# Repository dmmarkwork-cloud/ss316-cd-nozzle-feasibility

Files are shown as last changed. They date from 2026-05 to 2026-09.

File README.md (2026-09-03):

# SS316 Conical CD Nozzle: Thermal, Structural & DFM Assessment

Multiphysics analysis of an uncooled stainless-steel converging-diverging nozzle. The study answers a single question: **can SS316 survive the combined thermal and pressure loading at the design operating point?**

The short answer is yes against yield, with a FoS near 7 rather than the 42.7 reported in v1.0, and the binding questions are the startup transient and creep.

> **This is v2.0.** It supersedes v1.0, which reported a factor of safety of 42.70 at the throat. That figure was wrong by approximately 6x for two independent reasons: the wrong location was assessed, and the assessed quantity was not a classified stress. v1.0 is preserved under tag v1.0 and is not overwritten. See What changed in v2.0.

---

## Headline results

| Metric | Value | Source |
|---|---|---|
| Governing location | **Chamber-to-converging junction, converging side, inner surface** | Report §5.6 |
| Governing quantity | linearised membrane + bending (M+B); von Mises, axisymmetric straight | Report §5.5 |
| Governing stress (Mesh J3) | **29.611** | Report §5.6.1 |
| Mesh band, J1 to J3 | 29.611 to 30.010 MPa | Report §6.2 |
| SS316 yield at 526.83 °C (interpolated) | 210.73 MPa | SSINA Table 1 / Nickel Institute 9004 |
| Factor of safety against SS316 yield | **7.12 with a band 7.02 to 7.12** | Report §5.6.1 |
| Creep driver, primary membrane S₁ | 9.914 MPa | 	Report §5.6.3 |
| Through-wall ΔT at the junction| 1.26 K | Report §5.7 |
| Free axial thermal expansion (total deformation) | 1.711 mm over 183.44 mm | Report §5.8 |
| CFD peak wall y+ | 	1.74 (viscous sublayer resolved) | Report §4.2 |
| CFD mass imbalance | 	3.0 × 10⁻⁵ % | Report §4.3 |
| Discharge coefficient | 0.977 | Report §4.4 |

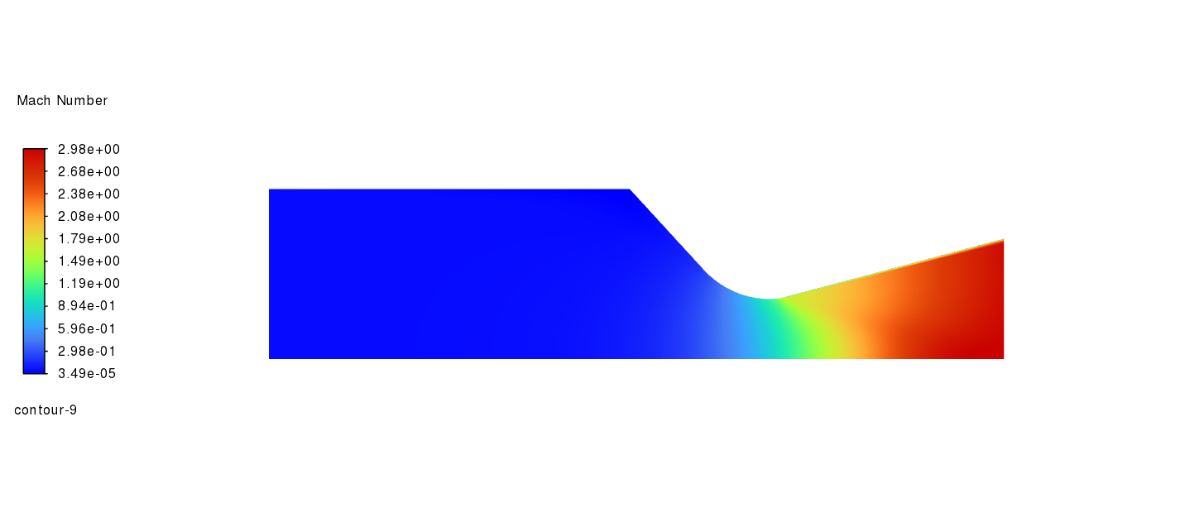
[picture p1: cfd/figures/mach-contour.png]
Mach number contour from the converged Fluent solution

**Mach number** contour from the converged Fluent solution Mach number contour, converged Fluent solution on the structured 88,800-cell mesh. Area-weighted exit Mach 2.85 against hand-calc 2.94, within 3.1% (validation gate passed). Peak 2.98 is the inviscid core value, not the bulk exit.

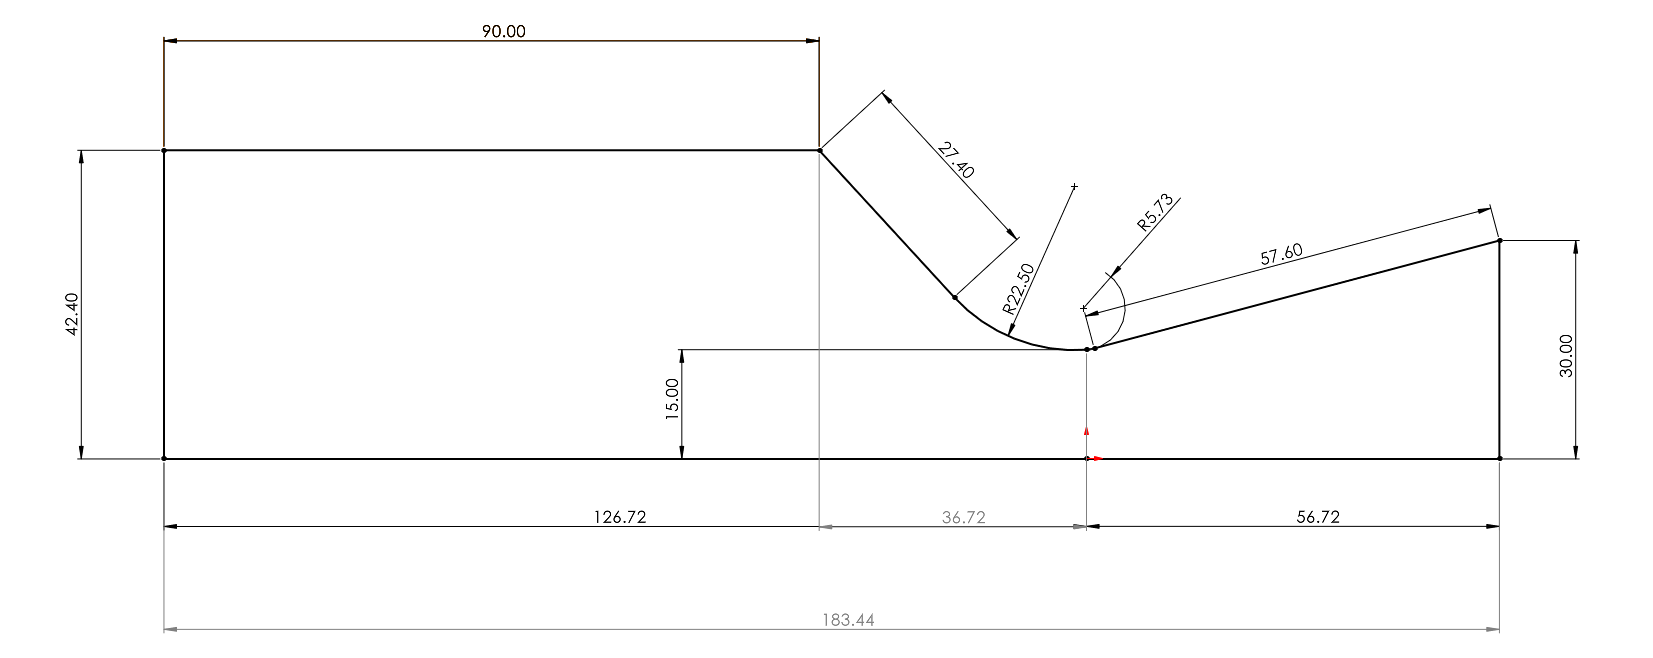
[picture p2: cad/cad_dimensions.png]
Nozzle half-section dimensions

**Nozzle half-section dimensions (mm)**. Throat radius 15 (nominal; as-built minimum 14.942 at −0.77 % area (see Geometry Freeze Disposition), exit radius 30 (ε = 4). Divergent side: 14.8° throat-to-exit chord angle (the straight diverging segment itself is 14.91°). Convergent side: a straight 47.43° taper from the chamber blended into the throat through an R22.5 arc. 4 mm wall.

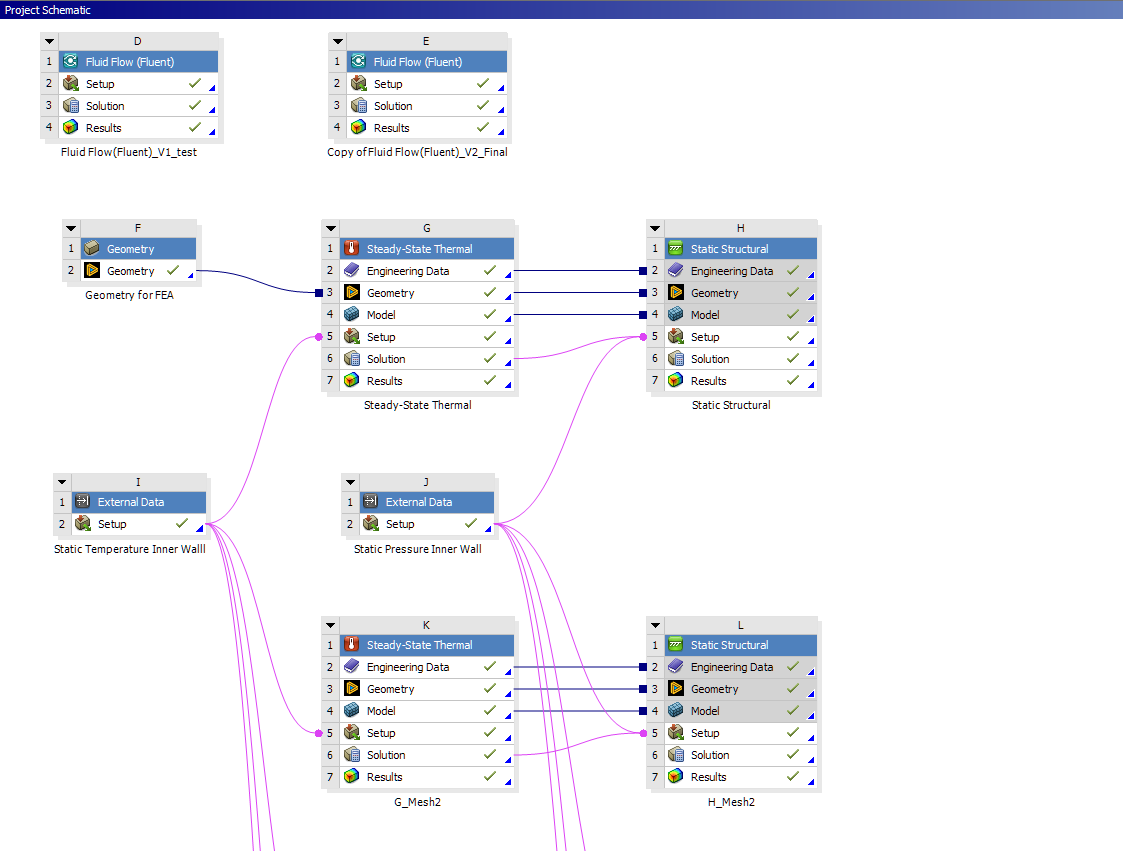
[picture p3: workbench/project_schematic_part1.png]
Workflow part 1

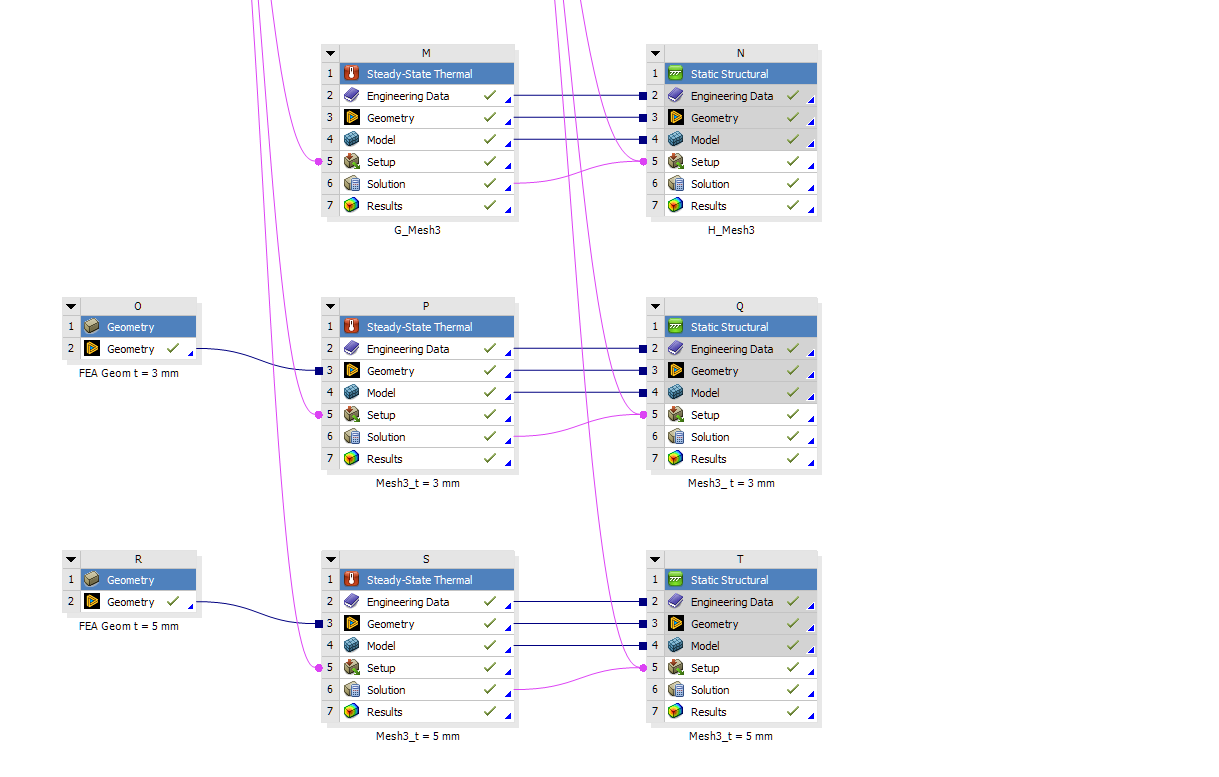
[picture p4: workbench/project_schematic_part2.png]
Workflow part 2

**One-way FSI chain:** two External Data systems feed a steady-state thermal and a static structural system, with explicit validation gates between phases.

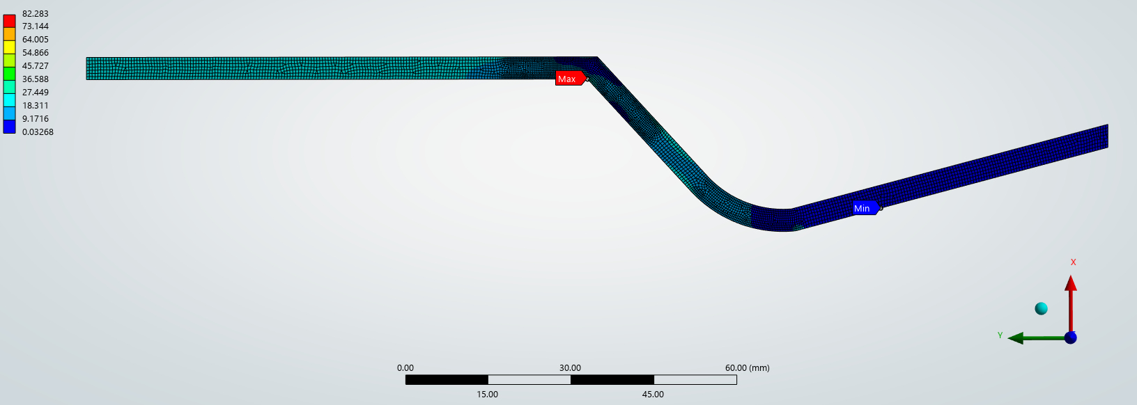
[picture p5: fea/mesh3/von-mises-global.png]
von Mises globa

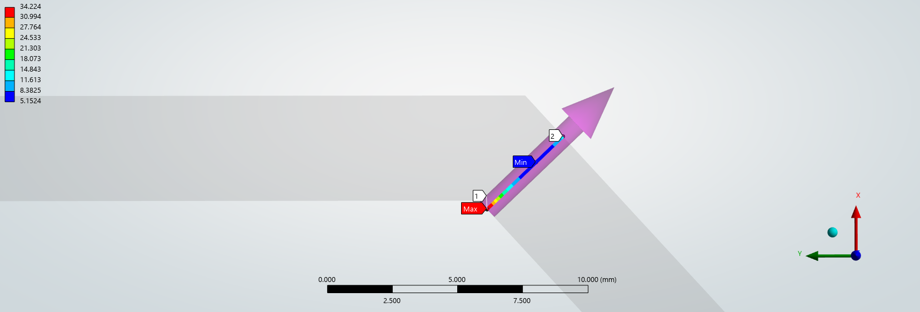
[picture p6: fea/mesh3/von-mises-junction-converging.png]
von Mises junction converging side

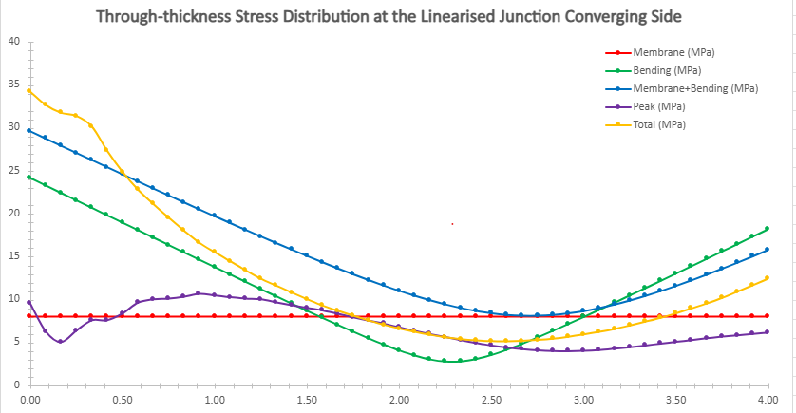
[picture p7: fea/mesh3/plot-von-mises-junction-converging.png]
von Mises junction converging side plot


**The 82.283 MPa maximum** is located at the unfilleted jucntion kink, is re-entrant and therefore singular, and is excluded from the assessment. The reported 29.611 is the linearised M+B (a seperate stress quantity that feeds combined tensor components into von Mises) on a through-thickness path adjacent to that corner. The v1.0 inlet-vertex displacement constraint singularity is absent; it was eliminated by moving the displacement constraint from a vertex to the full inlet edge.

**The binding failure modes are not yield.** The wall runs at approximately 527 °C at the junction, above the SS316 410 °C creep onset, with a non-relaxing primary membrane driver of 9.914 MPa. SS316 remains viable for short-duration prototype and ground-test firings at this operating point. Sustained or flight-rated operation requires the transient and creep work listed under Future work.

---

## Operating point

| Parameter | Value | Notes |
|---|---|---|
| Chamber pressure, P_c | 2 MPa | Working air, γ = 1.4 |
| Chamber temperature, T_c | 800 K | Within SS316 continuous-service limit (925 °C, oxidizing) |
| Exit pressure, P_e | 0.1 MPa | Sea-level design |
| Throat radius, R_t | 15 mm | |
| Area ratio, A_e/A_t | 4 | |
| Contraction ratio, A_c/A_t | 8 | From M_inlet ≤ 0.1 constraint (min ≥ 5.9) |
| Wall thickness, t | 4 mm | Baseline; sensitivity at 3/4/5 mm |
| Geometry | Conical C-D | Diverging straight taper 14.91° half-angle (14.8° throat-to-exit chord); converging straight taper 47.43° half-angle, blended into the throat by an R22.5 arc (no junction fillet). As-built, verified from CAD/STEP — see `docs/Geometry_Freeze_Disposition.md` |
| Material | SS316 | Uncooled, temperature-dependent properties |

All pressures reported in v2.0 are **absolute**. Any figure carrying a gauge scale belongs to v1.0.

**Material precedent:** the IJIRSET 2019 H₂O₂ monopropellant thruster (Deif et al.) uses SS316 in a similar uncooled configuration. Conditions differ (lower chamber pressure, smaller throat, pulsed, different working fluid), so it supports material precedent only.

---

## Tools & environment

| Phase | Tool | Notes |
|---|---|---|
| Hand calculations | Jupyter + handcalcs | Symbolic → numeric trace |
| CAD geometry | SolidWorks → SpaceClaim | 2D axisymmetric surface body |
| CFD | ANSYS Fluent 2026 | 2D axisymmetric, density-based coupled, k-ω SST |
| CFD mesh | ANSYS Meshing (classic); 2D Fluent system | Structured mapped quad, 444 × 200, 88,800 cells. Replaces Fluent Meshing in v1.0 |
| FEA | ANSYS Mechanical 2026 | Steady-state thermal + static structural |
| FEA Mesh | Fluent Meshing (CFD), Mechanical (FEA) | Quad-dominant, junction-refined ladder J1/J2/J3 |

---

## Analysis workflow

Six phases, each gated by validation against the previous phase.

| # | Phase | Status | Deliverable |
|---|---|---|---|
| 1 | Hand calculations (isentropic, area-Mach, T_aw) | Complete | `notebooks/cd-nozzle-handcalc-checkpoint.ipynb` |
| 2 | SolidWorks geometry (2D axisymmetric profile, 4 mm wall offset) | Complete | `cad/conical_v1_sketch.SLDPRT` |
| 3 | CFD: ANSYS Fluent, 2D axisymmetric, k-ω SST | Complete | `docs/Phase3_CFD_Summary.md` |
| 4 | FEA: one-way FSI → ANSYS Mechanical thermal-structural | Complete | `docs/Phase4_FEA_Summary_v3.md` |
| 5 | Mesh convergence study | Complete | `docs/Phase5_Convergence_Study_v2.md`, `notebooks/convergence_study_handcalc-checkpoint.ipynb` |
| 6 | Wall-thickness sensitivity study | Complete | `docs/Phase5b_Sensitivity_Study.md`, `notebooks/wall_thickness_sensitivity-checkpoint.ipynb` |

The one-way FSI uses Fluent wall outputs (static temperature, static pressure) mapped onto the FEA mesh through ANSYS Workbench **External Data systems**.

---

## Key findings

1. **The chamber-to-converging junction governs, not the throat.** At the unfilleted cylinder-to-convergent discontinuity, linearised M+B is 29.611 MPa against 17.183 MPa at the throat fillet: a 1.72x difference. 

2. **Bending dominates, and increasing thickness improves FoS, reversing the v1.0 trend.** Bending contributes 71 to 77% of M+B. Junction FoS is 4.62 / 7.12 / 10.18 for t = 3 / 4 / 5 mm. The v1.0 throat FoS values of 53.27 / 42.70 / 33.96 are withdrawn. Thermal bending is real but contributes only 4 to 16% at the junction. At the throat, the pressure state is anticlastic and nearly stress-free, leaving thermal stress as the dominant component there.

3. **The governing metric does not converge monotonically, so the result is reported as a band.** Governing von Mises M+B changes only −0.08% then −1.25% across J1/J2/J3.

4. **Steady-state thermal loading is small.** Natural convection accounts for 99.64% of the thermal resistance. Of the available 500 K wall-to-ambient difference, approximately 498 K occurs across the external film and only ~1 K across the wall.

5. **The same thermal boundary condition fails validation in the axial profile.** The imported wall temperature spans only 17 K, versus approximately 56 K expected from recovery theory, and exceeds the 800 K stagnation temperature by up to 9 K. Thus, a realistic axial thermal load is missing. At the junction, Saint-Venant decay bounds the consequence (91 mm extent vs. 13.3 mm decay length); in the divergent section, it does not. This is reported as a failed validation gate, not re-scoped into a pass.

6. **Seventeen FEA validation gates were applied, with two failures.** The validation included independent equilibrium checks: net axial thrust vs. CFD wall integral (0.20%) and axial membrane identity F/A_ring (0.001%). The two failed gates were throat path-length validation and imported wall temperature vs. recovery theory. Their consequences are explicitly bounded rather than hidden.

---

## The Design for Manufacturing (DFM) Package

The feasibility result above is only useful if the part can be made and inspected. The analysis is therefore carried into a **fabricable engineering package**: a GD&T'd, toleranced drawing set for the inlet joint, tolerance stack-ups that close against the frozen FEA geometry, a machining route, an inspection plan, a BOM, and a mock supplier RFQ.

**Scope** is a short-duration, ground-test prototype, quantities 1 to 5. Drawing set is ASME Y14.5-2018, first-angle, A2, issued Revision C (2026-08-13).

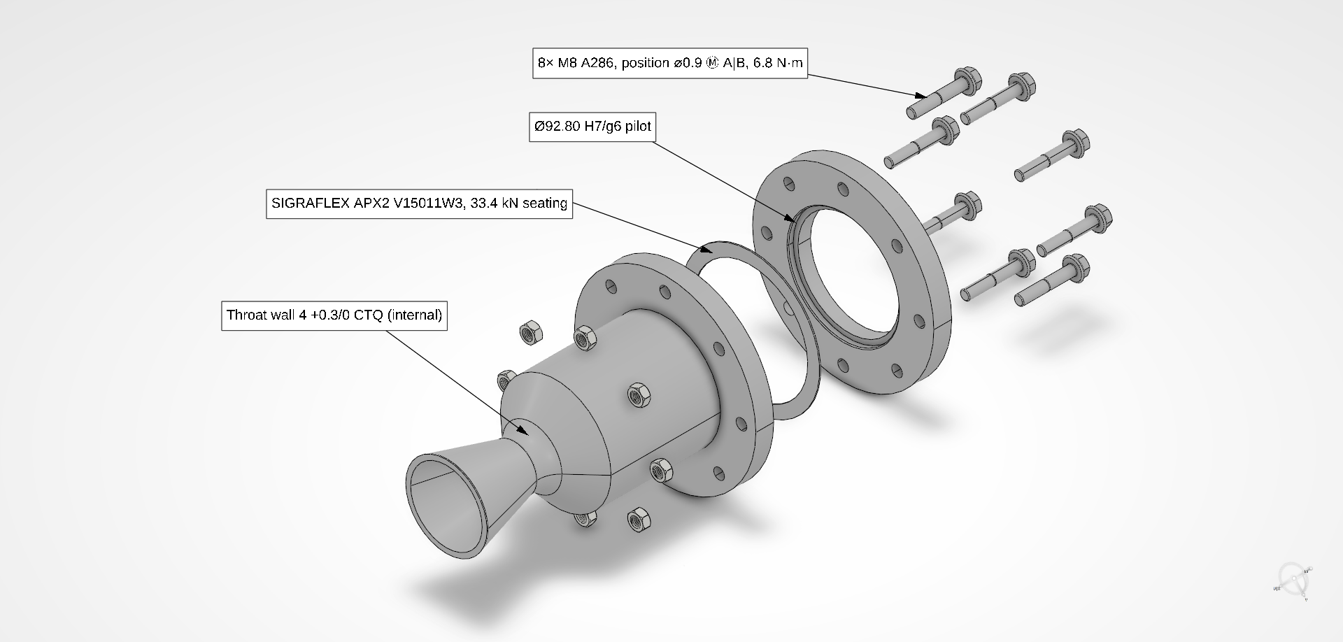
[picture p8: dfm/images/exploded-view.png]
Exploded view of the inlet joint assembly

Inlet-joint assembly (CDN-000). Nozzle body, flexible-graphite gasket, mounting flange, 8 x M8 A286 floating fasteners.

| Sheet | Part | Key controls |
|---|---|---|
| [CDN-001](dfm/drawing/CDN-001.pdf) | C-D Nozzle Body | frozen internal contour by surface profile 0.2 A\|B + total runout 0.05 A\|B; throat wall **4 +0.3/0 (CTQ)**; pilot Ø92.80 g6 |
| [CDN-002](dfm/drawing/CDN-002.pdf) | Mounting Flange | register bore Ø92.80 H7 with ⊥0.05 A; seat flatness 0.05 |
| [CDN-000](dfm/drawing/CDN-000.pdf) | Inlet-joint Assembly | ballooned BOM, interface notes, bolt torque 6.8 N·m cold |

### Four main decisions that carry this package

1. **Pilot locates, bolts clamp.** A single Ø92.80 H7/g6 locational-clearance fit centres the flange (Datum B); the 8 x M8 fasteners float and only clamp, positioned at MMC.
2. **The CTQ is the throat wall, and it is not a yield argument.** The 4 +0.3/0 band comes from creep life at ~530 °C, pressure-boundary minimum material, and machining minimum. The sensitivity study confirms the whole band is structurally free (FoS ≈ 40 across it), which is exactly why the tolerance had to be justified on other grounds.
3. **The stacks close, with margin.** Worst-case 1-D concentricity 0.060 mm against a 0.10 mm limit (1.68x); the bolt pattern assembles at strict MMC with no reliance on bonus tolerance.
4. **Every value is traceable.** Each dimension, tolerance and fit is tied to a source and a claim tier in the [value register](dfm/docs/value-register.md) and [`SOURCES.md`](dfm/sources/SOURCES.md), down to the gasket bolt load taken from ASME BPVC VIII-1 Mandatory Appendix 2.

**Full package: [`dfm/README-dfm.md`](dfm/README-dfm.md)**

---

## Scoping & limitations

- **No creep model.** The wall runs above the SS316 creep threshold. The driver is the primary membrane S₁ of 9.914 MPa, not the 29.611 MPa headline, because secondary bending relaxes under sustained load.
- **Steady-state only.** No transient startup/shutdown or thermal-fatigue/cyclic loading; The short-duration-firing conclusion does not cover cyclic life.
- **One-way FSI only.** No structural deformation feedback into CFD. Standard for preliminary analysis at this fidelity.
- **No junction fillet.** The sharp re-entrant corner makes Peak singular and mesh-dependent, so Peak and Total are excluded at that location. 
- **CFD rests on a single mesh** Iterative convergence demonstrated and five physical gates pass; discretisation error is not quantified.
- **Governing path is non-monotone under mesh refinement.** No valid Richardson order or GCI on the reported quantity. Reported as a band, 7.02 to 7.12.
- **Adiabatic-wall CFD → imposed T_aw on FEA.** Conservative; credits no wall-side conduction or radiation relief.
- **2D axisymmetric.** No asymmetric loads. Acceptable for axisymmetric geometry and required by the license cell cap.
- **Outer-wall convection h = 10 W/m²·K.** Still-air natural convection; conservative for a test stand where exhaust-plume entrainment would add convective relief.

---

## Operating point

| Parameter | Value | Notes |
|---|---|---|
| Chamber pressure, P_c | 2 MPa | Working air, γ = 1.4 |
| Chamber temperature, T_c | 800 K | Within SS316 continuous-service limit (925 °C, oxidizing) |
| Exit / back pressure, P_e | 0.060 MPa absolute | 60,000 Pa. Corrects the v1.0 record of 0.1 MPa; consistent with isentropic 59,574 Pa |
| Throat radius, R_t | 15 mm | |
| Area ratio, A_e/A_t | 4 | |
| Contraction ratio, A_c/A_t | 8 | From M_inlet ≤ 0.1 constraint (min ≥ 5.9), NASA SP-8120 |
| Wall thickness, t | 4 mm | Baseline, normal offset; sensitivity at 3/4/5 mm |
| Geometry | Conical C-D | 14.8° divergent half-angle; converging wall 46.25° from the axis, blended into the throat by an R22.5 arc; **no junction fillet** |
| Material | SS316 | Uncooled, temperature-dependent E and α |
| Allowable basis | Typical short-time values | Not specified-minimum. Flagged as future work |

All pressures reported in v2.0 are **absolute**. Any figure carrying a gauge scale belongs to v1.0.

Material precedent: the IJIRSET 2019 H₂O₂ monopropellant thruster (Deif et al.) uses SS316 in a similar uncooled configuration. Conditions differ (lower chamber pressure, smaller throat, pulsed, different working fluid), so it supports material precedent only.

---

## What changed in v2.0?

| # | Change | Effect |
|---|---|---|
| 1 | Governing location corrected: throat → chamber-to-converging junction | 8.602 → 29.611 MPa, 3.44x |
| 2 | Stress quantity corrected: body-scoped von Mises probe → linearized M+B | 4.917 → 8.602 MPa at the throat, 1.75x |
| 3 | **Combined effect on the headline** | **FoS 42.70 → 7.12** |
| 4 | Kinematic constraint: single vertex → full chamber-end edge | Constraint singularity removed; end-region M+B 91.34 → 19.54 MPa |
| 5 | Implementation of linearization set to Axisymmetric Straight on all objects | Converging-side M+B +12%; changed which side of the kink governs |
| 6 | Allowable evaluated at the governing-location temperature, 526.83 °C | 209.95 → 210.73 MPa |
| 7 | Mesh convergence re-scoped from throat to junction (J1/J2/J3) | Governing quantity now has convergence evidence, reported as a band |
| 8 | Thickness sweep re-scoped from throat to junction | Trend direction **reverses**; "FoS > 33 throughout" withdrawn; t = 3 mm gives 4.62 |
| 9 | FEA validation gates expanded from 3 to 17 | Two independent equilibrium closures, a formulation check, a thermal handoff check |
| 10 | CFD mesh replaced: unstructured hybrid (15,757 cells) → structured mapped quad (88,800 cells) | 100% quad, zero non-conformal interfaces, cell/node/face counts closed exactly |
| 11 | CFD near-wall clustering rebuilt: first cell 0.01 mm → 1.71 µm | Peak y+ 18 → 1.74; viscous sublayer resolved; retires limitation L1 |
| 12 | CFD mass imbalance 0.04% → 3.0 × 10⁻⁵ % | Three orders of magnitude |
| 13 | CFD pressure convention: gauge at 100 kPa reference → absolute at 0 Pa operating | Removes gauge/absolute ambiguity across all reported pressures |
| 14 | Discharge coefficient added as a CFD validation gate | Direct test of throat boundary-layer resolution; C_d = 0.977 |

**Why v1.0 was wrong but internally consistent** The v1.0 mesh convergence study was sound: four of five quantities of interest converged to within 1%. The assessment lies on a wrong probe scope, which is not a classified stress and not governing location. A converged wrong quantity is still wrong quantity. Therefore, investigating a non-governing location (throat) was not the correct approach and should have prompted a check of location and classification before publising.

---

## Repository structure

```
C-D-Nozzle/
├── README.md                                           # This file
├── docs/
│   ├── ss316_properties.md
│   ├── Geometry_Freeze_Disposition.md                  # Frozen as-built contour + deviation disposition
│   ├── Phase3_CFD_Summary.md
│   ├── Phase4_FEA_Summary_v2.md
│   ├── Phase4_FEA_Summary_v3.md
│   ├── Phase5_Convergence_Study_v2.md
│   └── Phase5b_Sensitivity_Study.md
├──dfm/
|   ├── calculations                                    # gasket loads, stack-up analysis and plot
|   ├── docs                                            # drawing data, specs, plans, records,  registers, decisions
|   ├── drawing                                         # official drawing sheets; CDN-000, CDN-001, CDN-002
|   ├── fair                                            # first article inspection request forms
|   ├── images                                          # isometric, inspection, and clash views
|   ├── revisions                                       # drawing sheet revision block records
|   ├── sources                                         # package source ledger (standards, materials, methods)
|   └── README-dfm.md                                   # DFM package summary
├── notebooks/
│   ├── cd-nozzle-handcalc-checkpoint.ipynb             # Phase 1
│   ├── convergence_study_handcalc-checkpoint.ipynb     # Phase 5
│   └── wall_thickness_sensitivity-checkpoint.ipynb     # Phase 6
├── cad/
│   ├── cad_dimensions.png
│   ├── conical_v1_sketch.SLDPRT                        # SolidWorks source 2D/3D
│   ├── conical_v1_sketch.STEP                  
│   ├── conical_v2_spaceclaim.sketch.scdocx             # SpaceClaim geometry
│   ├── inlet_side.png                       
│   ├── isometric.png                           
│   ├── outlet_side.png                        
│   └── right_side.png                          
├── cfd/
│   ├── case_data/                                      # CFD Fluent data and setup
│   ├── figures/                                        # results, plots, contours
│   ├── exports/                                        # wall_temperature_v2.xy, wall_pressure_v2.xy, BC, and loads
│   └── mesh/                                           # Mesh data
├── fea/
│   ├── mesh1/                                          # Solved figures (von Mises, ΔT, deformation) and Mechanical data in mesh 1
│   ├── mesh2/                                          # Solved figures (von Mises, ΔT, deformation) and Mechanical data in mesh 2
│   └── mesh3/                                          # Solved figures (von Mises, ΔT, deformation) and Mechanical data in mesh 3
├── workbench/
    ├── project_schematic_part1.png                     # Analysis workflow
    └── project_schematic_part2.png
└── report/
    └── ss316_nozzle_report.pdf                         # Comprehensive report of the project
```

---

## Related work

- **`gas-vessel-fea`** — prior portfolio piece. Pressure vessel mesh convergence study; same methodological framework applied to a simpler geometry.

---

## Author
Mark Lorenz Yamanaka · Tsukuba · 2026

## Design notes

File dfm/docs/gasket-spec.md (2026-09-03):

# Gasket Specification: Inlet Joint Seal

One consolidated spec for the inlet-joint gasket, so the model, the drawing BOM and the RFQ all draw from one source.

**Item:** CDN-000 BOM item 5. **Confirmed part: SGL SIGRAFLEX APX2 HOCHDRUCK V15011W3.**

> **Claim Tier**
> - **T1** verified against the frozen analysis
> - **T2** derivable/reproducible
> - **T3** engineering judgment, stated as such
> - **T4** strategy, never on the drawing

| Item | Value | Tier | § |
|---|---|---|---|
| Grade | SIGRAFLEX APX2 HOCHDRUCK V15011W3, inhibited reinforced graphite | T2 | 1 |
| Dimensions | Ø92.8 ID × Ø112.8 OD × 1.5 mm free, plain ring | T2 | 2 |
| Compressed, seated | ~1.0 to 1.1 mm | T2 | 2 |
| Effective width (b), reaction diameter (G) | 5.0 mm, 102.8 mm | T2 | 2, 6 |
| Seat temperature | ~527 °C in air, confined | T1 | 3 |
| Governing temperature limit | 580 °C, datasheet maximum | T2 | 4 |
| Seat finish | Ra 3.2 to 6.3 µm, serrated, not lapped | T2 | 5 |
| Bolt-load method | ASME BPVC VIII-1 App. 2, eq (1) and (2) | T1 | 6 |
| Gasket factors | m = 2.5, y = 3000 psi (20.7 N/mm²) | T2 | 6 |
| Operating load Wm1 | 32.74 kN | T2 | 6 |
| Seating load Wm2 | 33.40 kN, governs | T2 | 6 |
| Seating stress delivered | 20.7 N/mm² over 1615 mm² | T2 | 6 |
| Re-torque | 5.7 kN/bolt (6.8 N·m) before every firing | T3 | 7 |
| Open residuals | 527 °C air rating, binding design m/y | n/a | 9 |

---

## 1. Type and selection

A soft flat **ring gasket** cut from **reinforced flexible graphite**, in an **oxidation- and corrosion-inhibited** grade, with a stainless insert.

**Why graphite (Path A), chosen over a metal C-ring (Path B).** It seals at low seating load, conforms to a machined face, survives the hot section, and is a cheap **replaceable consumable**. It also follows premeditated package scope of frequent-disassembly, floating-fastener design. **Path B** was rejected as a larger redesign, finer seat finish plus a machined groove plus different seating factors, disproportionate to a short-duration prototype. Path B remains the documented upgrade path if ever the project needs a sealed-for-life joint. **(T3)**

**Confirmed grade: SGL SIGRAFLEX APX2 HOCHDRUCK V15011W3**, 1.5 mm. Multilayer build: 0.5 mm APX2 oxidation-resistant flexible-graphite foils plus 0.05 mm 316L stainless foils, adhesive-free. Carries both an oxidation inhibitor and a passive corrosion inhibitor per ASTM F2168-13. The reinforcement is **smooth 316L foil**, which the spec allows alongside tanged. **T2, datasheet.**

**There are equivalents if APX2 HOCHDRUCK is unavailable**: GraFoil, SIGRAFLEX UNIVERSAL. Note that UNIVERSAL publishes EN 13555 parameters only and would need ASME-format m/y from the manufacturer before it could drop into the Appendix-2 calculation.

## 2. Dimensions

| Parameter | Value | Basis · tier |
|---|---|---|
| Inside diameter | **Ø92.8** full-seat (see §2a) | T2 |
| Outside diameter | **Ø112.8** | gasket-seat band outer · T2 |
| Thickness, free | **1.5 mm** (1/16″) | design · T3 |
| Thickness, compressed and seated | **~1.0–1.1 mm** | compressibility 37 % (ASTM F36) · T2 |
| Effective seating width, **b** | **5.0 mm** | ASME App-2, flat facing · T2 |
| Reaction (mean) diameter, **G** | **102.8 mm** | · T2 |
| Form | **Plain annular ring, no bolt holes** | OD Ø112.8 sits inside the Ø128 bolt circle, so it is a ring gasket, not full-face · T2 |

The machined **flat seat** on the parts is **Ø92.8 → Ø112.8**, 10 mm radial, coplanar to the Ø152 OD with no raised step. Only the **gasket footprint** has two options.

### 2a. Footprint options: full seat vs. fillet-cleared

The real soft-graphite gasket is cut to the **full 10 mm machined seat** and conforms over the R1.5 spigot/seat corner fillet. That is **Option A**, the design and procurement intent and the **bolt-sizing basis**. In the CAD assembly the ring is pulled in to Ø95.8 so it sits on the flat and avoids a corner clash. That is **Option B**, a modelling convenience. Both are valid; the loads differ by a few percent, always in the safe direction.

| | **Option A, full seat** *(design / procurement / sizing)* | **Option B, fillet-cleared** *(CAD model)* |
|---|---|---|
| Gasket ID | **Ø92.8** | Ø95.8 (Ø92.8 + 1.5 on radius, clears the R1.5 fillet) |
| Gasket OD | Ø112.8 | Ø112.8 |
| Radial footprint | 10 mm | 8.5 mm |
| Effective seating width, **b** | 5.0 mm | 4.25 mm |
| Reaction diameter,  **G** | 102.8 mm | 104.3 mm |
| Wm1 operating | 32.7 kN | 31.0 kN |
| Wm2 seating | **33.4 kN** *(governs)* | 28.8 kN |

**Selected**: **Option A** for bolt sizing and the flange load path. It is the conservative, real-gasket case. **Option B's** small inner-corner pocket sits on the gas side of the seal and is intended: two clean face contacts, no clash.

## 3. Operating Duty

| Condition | Value | Tier |
|---|---|---|
| Seat temperature | **~527 °C** (≈ 800 K) | T1 |
| Working medium | **Air**, γ = 1.4 | T1 |
| Chamber pressure | **2 MPa** | T1 |
| Scope | **Short-duration / ground-test firing only** | T1 |
| Seat exposure | **Confined**, only the inner edge sees the gas | T2 |

## 4. Temperature Caveat (one of the limitations)

This is the tightest margin in the joint.

The seat runs at **527 °C**. Four air ratings circulate in gasket literature and they describe different things, so only one governs here:

| Figure | Describes | Governs? |
|---|---|---|
| ~450 °C | **Bare, uninhibited** graphite in air | No, wrong material |
| ~510–525 °C | **Generic inhibited-grade** guidance, not tied to a product | No, superseded by the datasheet |
| **580 °C** | **APX2 HOCHDRUCK datasheet maximum**, the confirmed product | **Yes** |
| ~600 °C | **Confined-service** limit, edges only exposed, this joint's geometry | Yes, as the service condition |

Against the governing datasheet the seat is **below** the 580 °C maximum and **below** the ~600 °C confined limit, but **above** the datasheet's **"consult the manufacturer above 480 °C"** qualifier. That clause, not the temperature, is why a residual is carried in §9.

The margin rests on three conditions: the seat is confined with only the inner edge exposed, the firing is short-duration ground test only, and the gasket is a replaceable consumable inspected for inner-edge recession at teardown. Inhibited grades lose **≤ 2 %/h even at 670 °C** against up to 40 %/h for plain foil, so recession is slow and inspectable. **(T2/T3)**

**Open residual:** a one-line manufacturer confirmation of 527 °C service in confined air. It does not change the bolt sizing.

## 5. Mating-Seat Requirements

**Ra 3.2–6.3 µm, serrated / stock finish, NOT lapped.** Soft graphite needs a tooth-like surface to grip; a lapped seat weeps. Called out on CDN-001 and CDN-002 per ASME B46.1. Recorded as decision **C-4** in [`inlet-joint-design-record.md`](inlet-joint-design-record.md). **T2.**

> **Note** the distinction the drawing has to carry: **flat** is the seat *geometry*, **serrated** is the seat *finish*. They are not alternatives.

## 6. Gasket Factors and Bolt Loads

**Method, T1**, verified verbatim against ASME BPVC VIII-1 (2021) Mandatory Appendix 2, eq (1) and (2):

$$W_{m1} = 0.785\,G^2 P + 2b\pi G m P \qquad\text{(operating)}$$
$$W_{m2} = \pi b G y \qquad\text{(seating)}$$

Effective width and reaction diameter per Table 2-5.2, flat gasket sketch 1a/1b: $b_0 = N/2 = 5.0$ mm, and since $b_0 \le 6$ mm, $b = b_0$ and $G$ = mean diameter.

**Factors, T2**, from the APX2 HOCHDRUCK V15011W3 datasheet, **ASTM columns**: **m = 2.5, y = 3000 psi (20.7 N/mm²)**.

**Design loads, Option A:**

$$W_{m1} = 0.785(102.8)^2(2.0) + 2(5.0)\pi(102.8)(2.5)(2.0) = 16.59 + 16.15 = \mathbf{32.74 \text{ kN}}$$
$$W_{m2} = \pi(5.0)(102.8)(20.68) = \mathbf{33.40 \text{ kN}}$$
$$W_{\text{gov}} = \max(W_{m1}, W_{m2}) = \mathbf{33.4 \text{ kN}} \quad\text{seating governs, because } y \text{ is high}$$

Within the **35 kN grade-robust envelope**, so a gasket substitution among qualifying products cannot invalidate the bolt sizing.

**Seating stress check.** Delivered stress over the effective area $\pi G b$ = 1615 mm² is **20.7 N/mm²**, inside the datasheet window (minimum assembly 20, maximum 270 at 20 °C, 210 at 300 °C). Seated, not crushed. **T2.**

Reproduced by [`gasket_loads.py`](../calculations/gasket_loads.py).

### Why the factors are datasheet-sourced, not code-tabulated

Flexible graphite is not in ASME Table 2-5.1; that is the asbestos-era table, and its nearest row (mineral fiber with binder) is a different material at a different seating stress. Values of m and y are product- and thickness-specific rather than grade-independent: real reinforced-graphite products range across 2.0/2000, 2.6/2500 and 2.5/3000. The factors above therefore come from the confirmed product's datasheet, and the bolts are sized to a 35 kN envelope rather than to one vendor's number.

## 7. Handling, life and risks

| # | Item | Requirement |
|---|---|---|
| n/a | **Consumable** | Renew at each disassembly. Re-torque on reassembly: graphite consolidates, so preload relaxation is the managed loss path, not the metal. |
| R1 | Inner-edge oxidation | Life-limiting, not sudden. Inhibited grade + consumable replacement + teardown inspection of recession. |
| R3 | Preload relaxation | Managed by the re-torque protocol below plus replacement. Datasheet: residual stress ≥ 45/50 N/mm², 90 % retained after 16 h at 300 °C per **DIN 52913**; hot creep < 3 %. **T2, at 300 °C.** |
| R6 | Galvanic couple, graphite to SS316 | Graphite is **cathodic** to SS316, so with moisture it can pit the flange faces. Specify a corrosion-inhibited grade **and keep the joint dry between tests.** |

**Re-torque protocol (T3).** Re-torque all 8 bolts to assembly preload **$F_0 \approx 5.7$ kN/bolt before every firing**, verify residual, and **replace the gasket at each teardown**:

$$T = k F_0 d = 0.15 \times 5700 \text{ N} \times 0.008 \text{ m} = 6.84 \approx \mathbf{6.8 \text{ N·m} \;(60 \text{ lbf·in})} \text{ cold}$$

at a nickel-anti-seize $k \approx 0.15$. This is the CDN-000 note N1 torque.

The protocol bounds accumulated relaxation to a **single short firing**, minutes against the datasheet's 16-hour test, and the heating-induced metal tightening (+2.6 to +10.5 kN/bolt) works in the sealing direction and further offsets it.

## 8. BOM Callout: CDN-000 Item 5

Gasket, reinforced flexible graphite, oxidation- and corrosion-inhibited, 316L SS multilayer reinforcement; ring type, Ø92.8 ID × Ø112.8 OD × 1.5 mm. Confirmed part: SGL SIGRAFLEX APX2 HOCHDRUCK V15011W3 (or equivalent publishing ASME m/y and rated for the service temperature). **Replaceable consumable.**

## 9. Open residuals

Both reduce to one manufacturer enquiry. Neither changes the bolt sizing, and both are stated rather than hidden.

| Item | Status |
|---|---|
| **527 °C air rating** | Datasheet maximum is 580 °C with oxidation ≤ 2 %/h at 670 °C, but it says "consult manufacturer above 480 °C." Confined-air service at 527 °C needs a one-line confirmation. |
| **Binding design values** | The published m/y are "typical, non-binding; contact technical sales for design." Adequate for a portfolio package at T2; obtain binding values for real procurement. |

---

## Sources

- **S13** method:
    - ASME BPVC VIII-1 (2021) Mandatory Appendix 2, §2-5 eq (1)/(2), Tables 2-5.1 and 2-5.2, verified against a licensed copy (**T1**, cited by identifier; code scans are not committed to this repo)
- **S13** factors:
    - SGL SIGRAFLEX APX2 HOCHDRUCK datasheet, grade V15011W3, ASTM columns m = 2.5 / y = 3000 psi (**T2**)
    - [SIGRAFLEX APX2 datasheet](https://www.sglcarbon.com/pdf/SGL-Datasheet-SIGRAFLEX-APX2-APX-BP-B-SHL-N-Foil-US.pdf)
    - [SGL SIGRAFLEX gasket sheets](https://www.sglcarbon.com/en/markets-solutions/material/sigraflex-unreinforced-and-reinforced-graphite-gasket-sheets-made-from-flexible-graphite/)
- **S15** flexible-graphite grades and oxidation limits:
    - [NeoGraf GraFoil](https://www.neograf.com/products/gaskets-sealants/grafoil-flexible-graphite/); RAM Gaskets, Kaxite, GasketSales
- **S5** ASME B46.1:
    - surface texture for the mating seat
- **S11** frozen operating conditions:
    - [`Phase4_FEA_Summary_v3.md`](../../docs/Phase4_FEA_Summary_v3.md)

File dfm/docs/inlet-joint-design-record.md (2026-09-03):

# Inlet Bolted-Joint Design Record

Every resolved decision for the inlet flange joint (register fit, gasket, bolting, flange geometry), each with its source and claim tier.

**Governing rule:** nothing is "closed" while it rests on an unconfirmed source or contradicts another live record.

**Frozen operating conditions:** Pc = **2 MPa** (working air, γ = 1.4), Tc = **800 K**; mount-end chamber bore **Ø84.80**; inlet/chamber wall ≈ **527 °C**. **(T1)**

> **Claim Tier**
> - **T1** verified against the frozen analysis
> - **T2** derivable/reproducible
> - **T3** engineering judgment, stated as such
> - **T4** strategy, never on the drawing

| Item | Value | Tier | § |
|---|---|---|---|
| Gas bore | Ø84.80 | T1 | C-1 |
| Register land | Ø92.80 = bore + 2 × 4.00 wall | T2 | C-1 |
| Register fit | H7/g6, clearance +0.012 / +0.069 | T1 | C-2 |
| Spigot projection | 4.75 mm | T3 | C-1 |
| Register engagement, seated | 2.5 mm | T3 | C-1 |
| Gasket seat | Ø92.80 → Ø112.80 flat band, R1.5 inner fillet | T3 | C-1 |
| Clearance hole | Ø9 +0.22/0 (H13) | T1 | C-3 |
| Seat finish, pilot finish | Ra 3.2 to 6.3 µm, Ra 0.8 to 1.6 µm | T2 / T3 | C-4 |
| Gasket factors | m = 2.5, y = 3000 psi | T2 | C-5 |
| Governing bolt load | 33.4 kN seating (Wm2) | T2 | C-5 |
| A286 hot yield at 527 °C | 582 MPa | T2 | C-6 |
| Fasteners | 8 × M8 A286, applied 114 MPa (20 % of hot yield) | T2 | D-1 |
| Preload | 5.7 kN/bolt = 157 MPa (27 %), torque 6.8 N·m cold | T2 | D-1 |
| Bolt circle, flange OD, thickness | Ø128, Ø152, 15 mm | T3 | D-2 |
| Bolt-pattern position | ⌀0.9 Ⓜ → A\|B | T2 | D-2 |
| Datum scheme | A = mating face, B = pilot Ø92.80, no C | T3 | D-3 |
| Cross-part concentricity | 0.060 mm against ≤ 0.10 (1.68×) | T2 / accept T3 | D-3 |

---

## 1. The joint as built

A two-part bolted inlet joint. The **nozzle body** (Part 1) carries a projecting pilot register (spigot), a flat gasket seat, and a bolt flange at the mount end. A **mounting flange ring** (Part 2) registers on the pilot and clamps the gasket. Male pilot on the body, female recess in the ring, floating fasteners.

| Feature | Value |
|---|---|
| Gas bore (ID) | **Ø84.80** |
| Spigot OD, datum B | **Ø92.80 g6**, projecting **4.75 mm** upstream → **2.5 mm** register engagement |
| Register bore, Part 2 | **Ø92.80 H7**, recess depth **4.5 mm** |
| Gasket seat | **Ø92.80 → Ø112.80** flat band (10 mm radial), Ra 3.2–6.3 µm serrated |
| Corner fillet | **R1.5** where the spigot meets the flat seat |
| Bolt circle | **Ø128** basic |
| Flange OD | **Ø152** |
| Flange thickness | **15 mm** |
| Fasteners | **8 × M8 A286**, Ø9.0 clearance holes both parts, nut behind |
| Gasket | Oxidation- and corrosion-inhibited flexible graphite, **1.5 mm**, replaceable consumable |
| Governing bolt load | **33.4 kN** (seating, Wm2) |
| Bolt-pattern position | **⌀0.9 Ⓜ → A\|B**, both parts |
| Datum scheme | **A = mating face**, **B = pilot Ø92.80**, two-datum A\|B, no C |

---

## 2. Decision Records

### C-1 · Pilot register geometry

- **Gas bore Ø84.80**, read directly from the frozen STEP (2 × 42.40 chamber radius). **T1.**
- **Register land Ø92.80** = bore + 2 × 4.00 mm frozen wall. **T2.** The 4 mm wall is the derivation input and is stated explicitly for that reason.
- **Pilot fit surface** H7/g6 at Ø92.80, ISO 286. **(T1)**
- **Spigot projection 4.75 mm → register engagement 2.5 mm**, seated:

$$E = S - g_{\text{free}} - c = 4.75 - 1.50 - 0.75 = 2.5 \text{ mm}$$

  where $S$ = spigot projection, $g_{\text{free}}$ = free gasket thickness, $c$ = recess-mouth chamfer. **(T3)**

  The spigot was originally 4.00 mm. At that length the same subtraction gives **0 mm engagement**: the pilot would never enter the bore. Caught in the CAD assembly and corrected by lengthening to 4.75.

- **Gasket seat is a flat band, no collar or shoulder.** The Ø92.80 → Ø112.80 seat is coplanar with the seating face out to the Ø152 OD. The **R1.5 fillet sits at the inner corner** between the spigot and the seat, for stress relief and machinability. Bounded **R0.8–R2**: at least a standard turning-insert nose radius, at most what preserves the 10 mm seat width. **(T3)**

---
### C-2 · Register fit, H7/g6 at Ø92.80

ISO 286-1 **80–120 mm** size step. **(T1)**

| | Hole (H7) | Shaft (g6) |
|---|---|---|
| Deviations | +0 / +35 µm | −12 / −34 µm |
| Limits | Ø92.800 / Ø92.835 | Ø92.766 / Ø92.788 |

$$c_{\min} = +0.012 \text{ mm} \qquad c_{\max} = +0.069 \text{ mm} \qquad e_{\text{pilot}} = \tfrac{1}{2}c_{\max} = 0.0345 \text{ mm}$$

Sliding/location fit, never interference, good for frequent disassembly with no galling from a press. The 0.0345 mm is the **fit contribution only**, not a total concentricity budget; the runout contribution is allocated in D-3.

---

### C-3 · Clearance hole

M8 floating fastener → **Ø9.0 (H13)**, ISO 273:1979 medium series (fine 8.4, coarse 10.0). **(T1)**

The hole carries **size limits Ø9 +0.22/0** on the sheet. A position-at-MMC hole must have them, or the ⌀0.9 Ⓜ has no maximum-material condition and no bonus.

---

### C-4 · Gasket-seat surface finish

**Ra 3.2–6.3 µm (125–250 µin), serrated / stock finish, not lapped.** Soft graphite must bite into the roughness to seal; a lapped face can weep. Measured per ASME B46.1. **(T2)**

Two different finishes on one part: the Ø92.80 g6 pilot is a sliding-fit surface and takes a **finer** Ra 0.8–1.6 µm. Do not blanket one Ra over the part.

---

### C-5 · Gasket loads: ASME BPVC VIII-1 Appendix 2

**Method, T1**, verified verbatim against the 2021 code, eq (1) and (2):

$$W_{m1} = 0.785\,G^2 P + 2b\pi G m P \qquad W_{m2} = \pi b G y$$

Effective width and reaction diameter per Table 2-5.2 (flat gasket, sketch 1a/1b): $b_0 = N/2 = 5.0$ mm, and since $b_0 \le 6$ mm, $b = b_0$ and $G$ = mean diameter = 102.8 mm.

**Factors, T2:** SIGRAFLEX APX2 HOCHDRUCK V15011W3 datasheet, ASTM columns, **m = 2.5, y = 3000 psi (20.7 N/mm²)**.

**Result:** $W_{m1}$ = 32.7 kN (operating), $W_{m2}$ = **33.4 kN (seating)** → **seating governs**. Reproduced by [`gasket_loads.py`](../calculations/gasket_loads.py). Full spec in [`gasket-spec.md`](gasket-spec.md).

---

### C-6 · Bolt material and hot capacity

- Material: **A286 (ASTM A453 Gr 660 / AMS 5732, UNS S66286)**.
- Hot **0.2 % yield ≈ 582 MPa @ 527 °C**, interpolated between 595 @ 425 °C and 580 @ 540 °C. **(T2)** This is the governing sizing basis. Source is the TorqBolt published property table for the solution-980 °C / age-720 °C condition, which is the AMS 5732 condition on the BOM; AMS 5732 itself publishes no elevated-temperature curve. These are vendor **typical** values, not guaranteed minima. A minimum basis near ~520 MPa leaves bolt sizing unaffected. See **S14**.
- **CTE = 16.9 × 10⁻⁶/°C** (21–540 °C), close to SS316 (~16.5–18), so the register fit and preload hold through the thermal cycle. **(T2)**
- **Creep negligible:** onset ~380 MPa @ 540 °C (1 %/1000 h) against a preload stress of **~157 MPa**, a factor of ~2.4 below. **(T2)**
- **A4-70 rejected:** ISO 3506 rates it only to ~300 °C; a 527 °C value would be an extrapolation past the rated temperature, which is not defensible.

----

### D-1 · Bolt size and count

**8 × M8 A286** on the Ø128 bolt circle.

$$A_b = 8 \times 36.6 = 293 \text{ mm}^2$$

$$\sigma_{\text{applied}} = \frac{33\,400}{293} = 114 \text{ MPa} = 20\% \text{ of the 582 MPa hot yield}$$

$$F_0 = \frac{1.4\,W_{m1}}{8} = 5.7 \text{ kN/bolt} \quad\Rightarrow\quad \sigma_0 = \frac{5700}{36.6} = 157 \text{ MPa} = 27\% \text{ of hot yield}$$

Bolt spacing **6.28 × d** on the Ø128 circle, taken on the 50.27 mm arc pitch, which is the pitch the TEMA check in D-2 consumes (the chord between adjacent holes is 48.98 mm = 6.12 × d). Sized to a **35 kN envelope** so any qualifying reinforced-graphite grade lands inside it and a gasket substitution cannot silently invalidate the calculation.

**Eight chosen over more or fewer** to serve the frequent-disassembly priority (few fasteners to service) while keeping gasket-stress distribution acceptable.

**A286 galls**, so the torque spec is set with an anti-seize k-factor, not a bare-thread table: $T = k F_0 d = 0.15 \times 5700 \times 0.008 = 6.8$ N·m cold.

### D-2 · Flange geometry

- Bolt circle **Ø128**, flange OD **Ø152**, clearance hole **Ø9**.
- Outer edge distance **12 mm = 1.5 × d** ✓. Inner bolt-hole edge to the gasket-seat band edge (Ø112.80) is **7.6 mm (< 1.5 × d)**, accepted: the seat is a **flat** band with no step, so this is a finish-zone boundary, not a structural one. **(T3)**
- **Bolt-pattern position tolerance**, floating fastener (**A-08**):

$$T = H - F = 9.0 - 8.0 = 1.0 \text{ mm at MMC}$$

  Tightened to **⌀0.9 Ⓜ** so assembly is guaranteed independent of MMC bonus: the pilot float would otherwise consume the ⌀1.0 clearance at strict MMC.

$$T_{\text{safe}} = (H - F) - 2 e_{\text{pilot}} = 1.000 - 2(0.0345) = 0.931 \;\to\; \varnothing 0.9$$

- **Flange thickness 15 mm is governed by gasket uniformity, not bending.** Bending is non-governing (FoS ≈ 6 at 15 mm). The thickness is set so the flange stays rigid enough not to bow between the 8 bolts and unload the gasket.
- The `15` from Datum A to the chamber inlet face is dimensioned **basic** on CDN-001, so the profile-of-a-surface chain has a continuous basic path from Datum A to the internal contour. The frozen `90` chamber length then stacks basic behind it. Value and basis unchanged; only the dimensioning type.

> **Method-validity flag.** The 15 mm is quantified with the TEMA bolt-spacing relation $B_{s,\max} = 2d + 6t/(m+0.5)$. TEMA is a heat-exchanger standard, used here as a recognised quantification of the general gasket-uniformity principle. That is a method-validity judgment (R5), not a nozzle-specific code, and it is flagged rather than hidden.

> **Thickness held at 15 mm at m = 2.5. DECIDED (T3).** The rule closes at m = 2.0 ($B_{s,\max}$ = 52.0 mm ≥ 50.27 mm pitch) but not at the confirmed m = 2.5 ($B_{s,\max}$ = 46.0 mm, which would ask for $t \ge 17.1$ mm). The thickness is held because TEMA is a screening proxy for gasket-stress uniformity, not a strength check, and the governing structural check is unchanged at FoS ≈ 6. The unloading it guards against is bounded by the re-torque protocol and by heating tightening the joint (+2.6 to +10.5 kN/bolt) over a short-duration ground test.
>

### D-3 · Datum scheme and cross-part concentricity

- **Two-datum A|B** (A-09). **Datum A = mating face**, primary, seats flat, controls tilt. **Datum B = pilot Ø92.80**, secondary, centres, carrying **⊥ 0.05 → A**. 
- **Alignment control = total runout** of the internal contour → A|B. Surface **T1**, value **T3**. Position of a throat axis was rejected: the throat is a contour, not a clean feature of size, so a derived axis is ill-defined.
- **Pilot locates, bolts only clamp.** The bolt-pattern position is sized by fastener clearance and does not enter the concentricity control. No redundant location.
- **Cross-part concentricity stack**, worst-case 1-D radial:

$$e_{\text{WC}} = \underbrace{0.0345}_{\text{pilot float}} + \underbrace{0.0250}_{\text{runout, }\varnothing 0.05 \text{ TIR}} = 0.0595 \approx 0.060 \text{ mm} \;\le\; 0.100 \text{ mm} \quad (1.68\times)$$

  The 0.10 mm acceptance is **T3** engineering judgment with a written basis: it holds thrust-vector cant under 0.03° over the 198.44 mm length. See [`interface-control-plan.md`](interface-control-plan.md) §5.

---

## 3. Seal selection: Path A vs Path B

The gasket seat runs at ~527 °C in working **air**. Bare flexible graphite oxidises in air above ~450–500 °C; confined in a flange with only the edges exposed, the effective limit rises to ~600 °C. At 527 °C confined, graphite is workable but life-limited by inner-edge oxidation, which forced an explicit seal decision.

| Path | Verdict | Basis |
|---|---|---|
| **A. Oxidation-inhibited flexible graphite, replaceable consumable** | **CHOSEN** | Inhibited grades are rated ~510 °C+ in air and lose ≤ 2 %/h even at 670 °C against up to 40 %/h for conventional foil. Only the inner edge sees gas, so recession is slow and inspectable. Leaves bolts, flange, register and seat finish unchanged. |
| B. Metal seal (C-ring, spring-energized, or lapped metal-to-metal) | Not chosen | Removes the oxidation life-limit, but needs a finer seat finish across the whole seat, a machined groove at tight tolerance, and different seating factors. Larger redesign, higher cost, less forgiving of surface defects. |

Path A holds provided its conditions do: an oxidation- **and** corrosion-inhibited grade, a set replacement interval, logged inner-edge recession at teardown, and the joint kept dry between tests. **Path B is the documented upgrade path** if the article ever requires a sealed-for-life joint.

---

## 4. Risk register

| # | Risk | Status and mitigation |
|---|---|---|
| R1 | **Graphite inner-edge oxidation** | Life-limiting, not sudden. Inhibited grade + consumable replacement + teardown inspection of recession. |
| R2 | **Radial thermal gradient in the flange** | Thermal hoop stress reaches SS316 hot yield if the bore-to-OD ΔT exceeds ~120 °C. Secondary and self-limiting: exceeding yield means local plasticity and shakedown, not burst. The real consequence is low-cycle thermal fatigue at the inner edge over repeated firings. **Deferred** to the analysis repo as a cyclic-life item, outside DFM scope. |
| R3 | **Gasket preload relaxation** | The real preload-loss path, not the metal. Managed by re-torque on every assembly plus gasket replacement, not set-and-forget. |
| R4 | **Differential thermal expansion, metal** | **Resolved.** SS316 members expand more than the A286 bolt, so heating *tightens* the joint (+2.6 to +10.5 kN/bolt) and bolt stress stays under yield in every case. Not a relaxation risk. |
| R5 | **Method-validity flags** | Appendix-2 m/y is a *room-temperature* seating model used at 527 °C; TEMA is a *heat-exchanger* rule used on a nozzle flange. Both are stated T3 assumptions. TEMA does not close at m = 2.5; thickness held per §D-2. |
| R6 | **Galvanic couple, graphite to SS316** | Graphite is cathodic to SS316; with moisture it can pit the flange faces. Specify a corrosion-inhibited grade and keep the joint dry between tests. |
| R7 | **Rear-nut wrench access** | Checked in the CAD assembly: the nut on the body back-face at Ø128 clears with a standard or thin-wall 13 mm socket. Inboard 8.6 mm, socket-to-socket 32 mm, outboard to flange OD 3.0 mm (4.0 thin-wall). An impact socket is marginal at 1.5 mm. |

---

## 5. Tier summary

| Item | Tier | Note |
|---|---|---|
| C-1 bore Ø84.80 | **T1** | frozen STEP read |
| C-1 register land Ø92.80 | **T2** | bore + 2 × 4 mm wall |
| C-1 engagement + datum B | **T3** | design |
| C-1 gasket seat Ø112.80 flat + R1.5 fillet | **T3** | design |
| C-2 H7/g6 deviations | **T1** | ISO 286-2, 80–120 mm step |
| C-2 pilot float 0.0345 | **T2** | fit-only |
| C-3 clearance hole Ø9 | **T1** | ISO 273 M8 medium, H13 |
| C-4 Ra 3.2–6.3 serrated | **T2** | ASME B46.1 + finish rationale |
| C-5 method, ASME App-2 | **T1** | verified verbatim vs the 2021 code |
| C-5 m, y, design load | **T2** | APX2 HOCHDRUCK datasheet → governing 33.4 kN |
| C-6 A286 hot properties | **T2** | datasheet |
| C-6 ASME II-D allowable | — | omitted; untraceable to a primary source, was non-governing |
| D-1 bolt sizing | **T2 / T3** | calculation / choice |
| D-2 flange geometry | **T3** | design + TEMA method flag; thickness **held at 15 mm** at m = 2.5, §D-2 |
| D-2 position tol ⌀0.9 Ⓜ | **T2** | T = (H − F) − 2·e_pilot, bonus-independent |
| D-3 datum scheme A\|B | **T3** | two-datum, no clocking |
| D-3 concentricity stack | **T3** | 0.060 mm vs ≤ 0.10 acceptance |

---

## Sources

- **S11** frozen geometry and conditions:
    - [`Geometry_Freeze_Disposition.md`](../../docs/Geometry_Freeze_Disposition.md), frozen STEP
- **S4** limits and fits:
    - ISO 286-2 (H7/g6), ISO 273 (clearance holes)
- **S5** ASME B46.1:
    - surface texture; gasket-seat Ra from gasket-handbook practice
- **S13** ASME BPVC VIII-1 Mandatory Appendix 2:
    - flange bolt-load method, eq (1)/(2), Table 2-5.2
    - gasket m/y from the SIGRAFLEX APX2 HOCHDRUCK V15011W3 datasheet
- **S14** A286 / ASTM A453 Gr 660:
    - hot yield / CTE / creep vs temperature from the TorqBolt published property table, solution-980 °C / age-720 °C condition = the AMS 5732 condition; vendor typical values, not minima. The governing sizing basis
    - AMS 5732 cited for the material spec and heat-treatment condition only; it publishes no elevated-temperature yield curve
    - ASME BPVC II-D allowable, omitted (untraceable to primary source); Table Y-1 remains the T1 upgrade path for the hot-yield figure
- **S15** flexible-graphite oxidation limits:
    - air vs confined service, inhibited grades

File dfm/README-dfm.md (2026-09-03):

# Manufacturing Package (DFM)

The analysis above is carried into a **fabricable engineering package**: a GD&T'd, toleranced drawing set for the inlet joint, with tolerance stack-ups that close against the frozen FEA, a machining route, an inspection plan, a BOM, and a mock supplier RFQ. 

Scope = **short-duration / ground-test prototype (qty 1–5)**.

Drawing set = **ASME Y14.5-2018, first-angle, A2, issued Rev C (2026-08-13)**:

| Sheet | Part | Key controls |
|---|---|---|
| [CDN-001](drawing/CDN-001.pdf) | C-D Nozzle Body | frozen internal contour by **surface profile 0.2 A\|B + total runout 0.05 A\|B**; throat wall **4 +0.3/0 CTQ**; pilot Ø92.80 **g6** (Datum B); 8× Ø9 +0.22/0 on Ø128 basic, position **⌀0.9 Ⓜ A\|B** |
| [CDN-002](drawing/CDN-002.pdf) | Mounting Flange | register bore Ø92.80 **H7** (Datum B) with **⊥0.05 A**; recess 4.5 (tip-floor stack); matching bolt pattern; seat **flatness 0.05**, outboard face **∥0.05 A** |
| [CDN-000](drawing/CDN-000.pdf) | Inlet-joint Assembly | ballooned BOM + interface notes; bolt torque **6.8 N·m** cold, nickel anti-seize; gasket as replaceable consumable |

## Key Decisions

1. **Two-part bolted inlet joint; one pilot fit**.
    - Pilot Ø92.80 H7/g6 locational-clearance fit centres the flange (Datum B).
    - 8 × M8 floating fasteners only clamp, positioned at MMC.
    - Pilot locates, bolts clamp.
2. **Datum scheme A\|B, no clocking**.
    - Datum A = seal face (primary, controls tilt, sets the axial position)
    - Datum B = pilot (secondary, centres/locates radially)
    - Throat-to-mount coaxiality is held by total runout, selected deliberately over concentricity or composite profile.
3. **CTQ = throat wall (4+0.3/0)**.
    - Basis = creep life at ~ 530 °C + pressure-boundary minimum-material + manufacturing minimum.
    - Not a yield-margin argument (see sensitivity study in [ss316_cd_nozzle_report](report/ss316_cd_nozzle_report.pdf)).
    - Stack-up analysis confirms the band is structurally free (FoS ≈ 40 across it).

4. **Worst-case 1-D Stacks Close**.
    - Concentricity 0.060 vs ≤0.10 mm (1.68x).
    - 8-bolt pattern assembles at strict MMC independent of bonus (⌀0.9).
    - Spigot-tip/recess-floor gap = 0.45 mm after deepening the recess to 4.5 mm.

5. **Material + Route**.
    - Bar, ASTM A479/A479M-25 Type 316 (UNS S31600), solution-annealed, machined from Ø160 wrought bar.
    - Rejected casting and additive manufacturing (AM) at quantities 1–5 on property-basis, lead-time, and requalification grounds.
    - Scope is carried onto the BOM and RFQ.
6. **Seal**.
    - Reinforced flexible-graphite gasket
    - SIGRAFLEX APX2 HOCHDRUCK V15011W3
    - Bolt load per ASME BPVC VIII-1 Mandatory Appendix 2 (governing 33.4 kN, seating)
    - Replaceable consumable with a re-torque-before-firing protocol.

```mermaid
flowchart TD
    subgraph analysis["Analysis from SS316 C-D Nozzle Feasibility (frozen)"]
        cfd["CFD: wall p, T<br/> ANSYS Fluent, k-omega SST"] --> fea["FEA: throat stress<br/>ANSYS Mechanical, 4.92 MPa, mesh-converged"]
        fea --> sens["Wall-thickness sensitivity<br/>t = 3, 4, 5 mm"]
    end
    subgraph mfg["DFM Package"]
        ctq["CTQ callout<br/>4 +0.3/0 on CDN-001"] --> insp["Inspection plan;<br/>UT through-wall"]
        insp --> fair["FAIR Form 3<br/>AS9102B"]
    end
    sens --> ctq
    sens -.->|"band is structurally free<br/>FoS ~40 across band"| ctq
```

## Standards & QA

- ASME Y14.5-2018 - GD&T
- ISO 286-2 / ISO 273 - fits; clearance holes
- ASME B46.1 - surface texture
- ASME BPV VIII-1 Appendix 2 - gasket bolt load
- EN 10204 3.1 - mill certificate
- AS9102B - first-article inspection, planned FAIRs
- ASTM A967 - passivation
- [`SOURCES.md`](dfm/sources/SOURCES.md) - source and claim tier for every dimension, tolerance and fit

## Package Contents (`dfm/`)
- `dfm/drawing/` - the issued drawing set (PDF)
- `dfm/calculations/` - gasket loads and stack-up analysis calculations
- `dfm/docs/` - the [value register](dfm/docs/value-register.md) (every as-designed value with its source and tier), function and interface analysis, inlet-joint design record, drawing data, stack-ups, manufacturing, gasket spec, inspection plan, RFQ, and the method/assumption register
- `dfm/sources/` - the source ledger
- `dfm/fair/` - mock FAIR forms for each sheet
- `dfm/images/` - images of clash check, register engagement with gasket compressed/un-compressed, 3D assembly
- `dfm/revisions/` - full history of revisions

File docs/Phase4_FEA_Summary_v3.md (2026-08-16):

# Phase 4 FEA: Setup, Conditions and Results Summary (v3, Data Integrity Correction)
**Project:** SS316 Nozzle Feasibility · Pc=2MPa · Tc=800K · Rt=15mm · ε=4 · t=4mm
**Date:** 2026-05-10 · **Solver:** ANSYS 2026 R1 Student · **Model:** 2D Axisymmetric

Supersedes `Phase4_FEA_Summary_v2.md`. The v2 baseline FEA was solved against a stale CFD wall temperature export that remained in the External Data system after a CFD case re-run (Phase 3 Issue 5 lineage). The downstream Mechanical solve never received the updated upstream data because the External Data → Steady-State Thermal stream was not pushed after the source-file radio button was switched. This document records the diagnosis, the corrected solve, and the resulting QoI shifts. Engineering conclusions are unchanged.

---

## 1. Trigger: How the Stale Data Was Caught

During the Phase 5b sensitivity study setup at t = 3 mm, the Imported Temperature in Mechanical showed a Min source value of **790.29 K** instead of the v2 baseline-recorded 768.58 K. Cross-checking the Fluent CSV directly revealed that only one node, at the exit edge (X = +56.72 mm), differed between the two source files (805.72 K vs 767.85 K). The remaining 526 of 528 nodes were byte-identical.

The 38 K difference at the single edge node was sufficient to shift the mapped temperature field across the FEA mesh enough to change the throat probe stress by ~3%. The bulk wall temperature mean shift was 0.80 K with 1.84 K standard deviation across all nodes. That is small in absolute terms, but systematic and traceable to a defined upstream data event.

---

## 2. Root Cause

| Step | What happened |
|---|---|
| 1 | Original Phase 3 v2 CFD case + data was saved, validated, and exported (`wall_temperature_v2.xy`). |
| 2 | Case file was lost before Phase 4 began (Phase 3 Issue 5). CFD was re-run from the v2 mesh to reproduce the converged state. |
| 3 | Re-run produced a slightly different exit-edge node value (767.85 K vs the lost 805.72 K reference). All other nodes matched within solver noise (< 0.2 K). |
| 4 | Phase 4 v2 External Data system was set up. The CSV file was placed in the External Data location, but the source-file radio button selection in Workbench retained the earlier (pre-re-run) export path. |
| 5 | The "Update Stream Components" command was not invoked after the radio button toggle. Mechanical kept solving against the cached pre-re-run data through Phase 4 v2 baseline solve and all three Phase 5 mesh studies. |
| 6 | Phase 5b sensitivity setup forced a fresh External Data link, exposing the discrepancy in the Imported Temperature legend. |

---

## 3. Architectural Lesson: Pre-Solve Gate Update

The Phase 4 v2 pre-solve verification gate (Section 12.2 of the v2 document) checked imported load *spatial distribution* (chamber red, exit blue) but not *upstream freshness*. A spatially correct import can still be reading a stale file. The gate is updated for v3 with a freshness check.

### 3.1 v3 Pre-Solve Gate (additions in **bold**)

1. Imported Loads spatially spot-checked (chamber red, exit blue on pressure; throat hot, exit cold on temperature)
2. **Imported Loads numerical Min/Max recorded against expected baseline (v2 baseline: T 768.58–809 K, P −0.039 to 1.898 MPa). Any deviation >0.5 K or >0.005 MPa triggers upstream freshness check before solving.**
3. **External Data Setup cell right-clicked → "Update" before each fresh solve, then top-toolbar "Update Project" invoked to propagate downstream. Verified by Setup cell green-tick state.**
4. Convection BC value AND units re-confirmed in details panel
5. Reference temperatures consistent across Engineering Data / body / environment (all 20 °C)
6. Order-of-magnitude analytical estimates computed (Bi → ΔT, α·ΔT·L → δ, P·r/t → σ)
7. Post-solve: results compared against pre-solve estimates. Any deviation > 2× triggers root-cause investigation before proceeding.

### 3.2 Architecture improvement A3

| # | Change | Benefit |
|---|---|---|
| A3 | Imported Load Min/Max recorded as a versioned baseline value in this document, checked at every solve | Catches stale upstream propagation that v2 architecture (External Data via schematic links) did not detect on its own |

A1 (External Data via schematic links) and A2 (analytical pre-solve estimates) were necessary but not sufficient. A3 closes the remaining gap.

---

## 4. Corrected Imported Load Baseline (v3)

| Quantity | v2 recorded | v3 corrected | Δ |
|---|---|---|---|
| Imported Temperature Min | 768.58 K | 767.85 K | −0.73 K |
| Imported Temperature Max | 809.00 K | 808.17 K | −0.83 K |
| Imported Pressure Min | −0.039 MPa | −0.039 MPa | unchanged |
| Imported Pressure Max | 1.898 MPa | 1.898 MPa | unchanged |
| Source file (temperature) | `static temperature testing for FEA` | `wall_static_temperature_final.csv` (current re-run state) | re-linked |
| Source file (pressure) | `static pressure testing for FEA.csv` | `wall_static_pressure_final.csv` | unchanged |

Pressure import was unaffected. The stale-data issue was confined to the temperature stream.

---

## 5. Corrected Phase 5 Convergence Results

Re-run of all three meshes with corrected External Data link. See `Phase5_Convergence_Study_v2.md` for the full study; QoI table reproduced here for cross-reference.

### 5.1 QoI table (v3 corrected vs v2 recorded)

| QoI | v2 Mesh 1 | v3 Mesh 1 | v2 Mesh 2 | v3 Mesh 2 | v2 Mesh 3 | v3 Mesh 3 | Units |
|---|---|---|---|---|---|---|---|
| σ_vM,throat | 5.1924 | 5.0308 | 5.0321 | 4.8725 | 5.0773 | 4.9171 | MPa |
| σ_vM,global (singularity) | 267.06 | 267.06 | 352.61 | 352.62 | 430.57 | 430.58 | MPa |
| T_throat | 804.38 | 804.38 | 804.38 | 803.59 | 804.38 | 803.59 | K |
| ΔT_throat | 2.12 | 2.12 | 2.11 | 2.10 | 2.10 | 2.10 | K |
| δ_exit | 1.7161 | 1.7148 | 1.7161 | 1.7149 | 1.7163 | 1.7150 | mm |

### 5.2 Magnitude and direction of changes

- **σ_vM,throat:** systematic −3.1% across all three meshes. 
- **σ_vM,global:** unchanged to <0.1%. The singularity is constraint-driven, not thermally driven, so insensitive to the temperature field correction.
- **T_throat:** Mesh 1 unchanged at 804.38 K; Mesh 2 and Mesh 3 shifted to 803.59 K (−0.79 K). Within solver tolerance.
- **ΔT_throat:** essentially unchanged. Through-wall ΔT is governed by Bi, not absolute T_aw level.
- **δ_exit:** systematic −0.06% across all meshes. Exit deformation is dominated by α·ΔT·L integrated along the wall; small reduction consistent with cooler exit-edge load.

### 5.3 Convergence verdict

Convergence pattern is unchanged. 
    M1 → M2 step is −3.17% on σ_vM,throat;
    M2 → M3 step is +0.92%. Both within the same envelope as v2 (−3.09% / +0.89%). Mesh independence conclusion holds.

---

## 6. Updated Factor of Safety

Yield strength interpolation is unchanged (depends only on T_throat, which moved by 0.8 K). Throat T at 803.59 K = 530.44 °C → σ_y(530.44 °C) = 209.95 MPa.

$$\text{FoS}_{v3} = \frac{\sigma_{y,throat}}{\sigma_{vM,throat,M3}} = \frac{209.95}{4.9171} = 42.70$$

| | v2 | v3 |
|---|---|---|
| FoS at converged Mesh 3 | 41.3 | **42.7** |

Direction: marginally safer (+3.4%). Engineering interpretation unchanged: yield is not the binding constraint, creep is.

---

## 7. Engineering Conclusion (v3)

Unchanged from v2. Uncooled SS316 is not yield-limited at this operating point. The wall sits at 530 °C, above the SS316 creep threshold of approximately 410 °C. Time-dependent creep analysis is required to establish the binding limit. SS316 is viable for short-duration prototype or ground-test firings on yield grounds.

The data integrity correction shifted FoS by +3%; the engineering conclusion is not sensitive to the correction at this margin. This is itself a useful finding: it confirms that for FoS values of order 40+, ~1 K wall temperature noise in the imported load is well below the threshold of engineering significance. For lower FoS regimes (e.g., the t = 5 mm case in Phase 5b at FoS = 33.9), the same noise would be a larger relative contributor to uncertainty.

---

## 8. Updated Limitations Table

Adds L11 to the v2 limitations (and L12, logged 2026-08-12 from the downstream DFM package):

| # | Limitation | Impact | Mitigation |
|---|---|---|---|
| L1–L10 | Per Phase 4 v2 Section 11 | unchanged | unchanged |
| L11 | Imported Load freshness: single-node CFD export variability between re-runs | ~3% on throat stress, ~3% on FoS | A3 architecture: Min/Max baseline values now recorded and checked pre-solve |
| L12 | **Inlet-flange radial thermal gradient → low-cycle fatigue at the bore/fillet** (cyclic; distinct from throat-wall creep). First-order check (`Project_A/docs/phase4/thermal-gradient-calc.md`): elastic below ΔT ≈ 120 °C bore-to-OD, inner edge yields above. Actual ΔT unrun. | Fine for a few firings; life-limiting for repeated firing. | **Future work:** pin ΔT (thermal model or test thermocouple) + shakedown/LCF check (ASME VIII-2). If it governs, mitigate at bore fillet radius/finish (feeds DFM drawing CDN-001). |

---

## 9. File Trail

| File | Purpose |
|---|---|
| `Phase4_FEA_Summary.md` | Original v1; broken solve (3 BC errors) |
| `Phase4_FEA_Summary_v2.md` | v2 baseline; corrected BCs, stale upstream data |
| `Phase4_FEA_Summary_v3.md` | **This document; data integrity correction + freshness gate** |
| `Phase5_Convergence_Study.md` | Original Phase 5 (against v2 stale data) |
| `Phase5_Convergence_Study_v2.md` | Phase 5 re-run with corrected loads |
| `Phase5b_Sensitivity_Study.md` | Wall thickness sensitivity (t = 3, 4, 5 mm) using corrected loads |

---

## 10. Closing Note on Audit Trail

The v1 → v2 → v3 progression of this document is the deliverable, not the final v3 numbers in isolation. Each version corresponds to a class of failure mode caught:

- v1 → v2: BC unit and mapping errors (caught by Biot number sanity check)
- v2 → v3: Stale upstream data despite correct BC setup (caught by sensitivity study cross-check)

The pre-solve verification gate has been extended at each step. A4-class failures, whatever they turn out to be, will likely require A3 to be extended further. This is the expected pattern for a project of this complexity and is documented as such rather than papered over.

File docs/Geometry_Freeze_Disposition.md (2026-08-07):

# Geometry Freeze Disposition: SS316 Conical C-D Nozzle

**Purpose:** Establish the single frozen source of truth for the nozzle contour before the manufacturing/DFM package (Project A) is built on it, and formally disposition the deviations between the documented nominal geometry and the as-built CAD that was actually analyzed.

**Status:** FROZEN. As-built contour, use-as-is. See §4 for the disposition and §6 for the conditions.
**Compiled:** 2026-07-20
**Applies to:** `cad/conical_v1_sketch.SLDPRT`, `cad/conical_v1_sketch.STEP`, the CFD case (`cfd/case_data/residual_results.cas.h5`), and the FEA meshes (`fea/mesh*/`).

---

## 1. Why this note exists

Before freezing the geometry for drawing production, a documentation discrepancy on the converging half-angle had to be resolved (flagged in the Project A pre-execution review, item S3, and in the Geometry Workflow Record §10.1). On investigation the discrepancy was larger than a single wrong angle: the nominal design values stated in several documents, the coordinate table in the Geometry Workflow Record, and the as-built CAD were three different geometries.

Freezing a manufacturing drawing requires one authoritative contour. A profile-of-a-surface callout on the aerodynamic wall is only a true statement if it references the contour the analysis actually validated. This note records which contour that is, how it was verified, and how the deviation from the stated nominal is dispositioned.

---

## 2. What was verified, and how

The as-built contour was measured three independent ways and all three agree. This is direct measurement of the geometry files, not inference from documentation.

| Source | What was read | Method |
|---|---|---|
| `cad/conical_v1_sketch.STEP` | CARTESIAN_POINT, LINE, CIRCLE, TRIMMED_CURVE entities | Text parse of the STEP (AP214) file; angles/radii computed from the point and arc-center coordinates |
| `cfd/case_data/residual_results.cas.h5` | 15,951 mesh node coordinates; wall boundary = zone `convergin_throat_diverging` (465 nodes) | HDF5 read of `meshes/1/nodes/coords`; wall nodes extracted via the face→node connectivity |
| `fea/mesh2/mesh2_mesh_data.stl` | 34,762 mesh vertices | Binary STL parse; inner-wall contour = minimum radial coordinate per axial station |
| `cad/conical_v1_sketch.SLDPRT` | Converging taper angle, throat minimum radius | Opened and measured in SolidWorks; **confirmed by the author, 2026-07-20** |

**Cross-check result:** the CFD mesh wall matches the STEP contour to better than 0.1 µm in the throat-arc region; the FEA inner wall reaches the same 14.9420 mm minimum radius. The three analysis artifacts and the CAD describe the same contour. The concern that the May-4 STEP might be stale relative to the later SLDPRT is closed: the author has confirmed the SLDPRT reads the as-built values below.

*Claim tier: T1 (verified against the primary source: the geometry files themselves).*

---

## 3. Frozen geometry: the as-built contour

| Feature | Value | Basis / tier |
|---|---|---|
| Converging straight taper half-angle | **47.43°** | Measured, all three sources. T1 |
| Diverging straight taper half-angle | **14.91°** | Measured, all three sources. T1 |
| Diverging throat-to-exit chord angle | 14.81° | Geometric (throat 15 mm → exit 30 mm over 56.72 mm axial). This is the "14.8°" quoted in the README. T2 |
| Throat minimum radius (as-built) | **14.942 mm at x ≈ −1.6 mm** | Measured, all three sources. T1 |
| Throat radius (nominal design intent) | 15.00 mm at x = 0 | Project Definition / hand calc. T1 |
| Upstream throat blend arc | R 22.50 mm (1.5 R_t) | Measured; matches convention. T1 |
| Downstream throat blend arc | R 5.73 mm (0.382 R_t) | Measured; matches convention. T1 |
| Chamber radius | 42.40 mm (R_t·√8) | Design. T1 |
| Exit radius | 30.00 mm (R_t·√ε) | Design. T1 |
| Wall thickness (baseline) | 4.00 mm, offset radially outward | Design. T1 |
| Wall thickness (sensitivity) | 3, 4, 5 mm | Phase 5b. T1 |

**The frozen drawing basic contour is defined by the CAD/STEP coordinate table, not by the stated half-angle parameters.** For an aerodynamic surface this is the correct authority: the surface is a defined contour, and a profile-of-a-surface tolerance is applied to it. The half-angle numbers are descriptive, not the controlling definition.

---

## 4. Deviation disposition

Two deviations exist between the documented nominal design and the as-built/analyzed contour. Both are dispositioned **use-as-is**. Reasoning below.

### 4.1 Converging half-angle: nominal 30° → as-built 47.43°

The 30° value appears in the Project Definition and (before correction) in `Phase3_CFD_Summary.md`. The as-built taper is 47.43°. The Geometry Workflow Record separately derived 45° from its own coordinate table (§2.4/§10.1); that table does not match the CAD (its converging-line/arc junction is at (−15.91, 21.59); the CAD has it at (−18.184, 22.221)), so its 45° figure was arithmetic on an incorrect table, not a measurement of the CAD.

**Disposition: use as-is.** The converging section of a C-D nozzle is entirely subsonic. Its wall angle sets the chamber contraction profile, not the throat/supersonic performance that the analysis gates on. The CFD validation gate (area-Mach and isentropic checks) passed at the ~1–2.5 % level on this as-built geometry. A steeper contraction cone is aerodynamically benign here. No re-analysis is warranted: the deviation is a documentation error, now corrected, not a geometry defect.

*Note on convention:* the converging side is not a single cone. It is a straight 47.43° taper blended into the throat by the R22.5 arc. Describing it with a single half-angle is itself an approximation; the drawing controls it by the coordinate contour, not by an angle callout.

### 4.2 Throat minimum radius: nominal 15.00 mm at x = 0 → as-built 14.942 mm at x ≈ −1.6 mm

The two throat blend arcs are tangent to each other, but their common tangent point is tilted ~4.1° from the nozzle axis rather than lying at the axial throat plane. Consequently the true minimum flow radius is 14.942 mm and sits ~1.6 mm upstream of x = 0, instead of 15.00 mm exactly at x = 0.

**Quantitative impact (throat area):**

$$\frac{\Delta A}{A} = \left(\frac{14.942}{15.000}\right)^2 - 1 = -0.77\%$$

Assumptions: circular cross-section (axisymmetric); area governed by minimum radius. This is a straightforward geometric ratio, not a flow calculation.

**Disposition: use as-is.** A −0.77 % throat-area change is well inside the CFD validation band already accepted for this model (exit Mach agreement was within 2.5 %). Mass flow through a choked throat scales linearly with throat area, so the first-order effect on ṁ and thrust is likewise ≈ −0.77 %. That is below the fidelity of the present analysis and immaterial to the feasibility conclusion (FoS ≫ 1 against yield; creep-governed, not stress-governed). The offset comes from the arc-center placement of the original sketch. It is characteristic of the as-built part and is what was analyzed.

*Claim tier for both dispositions: the measurements are T1; the "use-as-is" engineering judgment is T3 (reasonable engineering judgment, stated as such). A formal mass-flow/thrust re-computation on the as-built contour would raise §4.2's impact statement to T2 but is not required for the feasibility scope.*

---

## 5. Governing-rule check (no re-analysis)

The project's standing rule is: *no re-analysis; if drawing work reveals an analysis problem, log it as an issue.* This disposition complies:

- Nothing here re-opens or re-runs the CFD or FEA. Reading the existing mesh and CAD files to identify which contour was analyzed is verification of the input, not re-analysis.
- The deviations are dispositioned against the **already-completed** validation results, not against a new run.
- The frozen contour for drawings is the analyzed contour, so the analysis→drawing traceability chain is preserved and honest.

If a future higher-fidelity study (e.g. the Bartz-BC follow-up already in Phase 5b future work) re-computes performance, the −0.77 % throat-area note in §4.2 should be revisited then. It is logged here as a known open item, not acted on now.

---

## 6. Freeze conditions and downstream actions

**Frozen for Project A drawing production:** the as-built CAD/STEP contour in §3, wall thickness t = 4.00 mm, maximum 3 parts.

Actions taken with this freeze:
1. `docs/Phase3_CFD_Summary.md` corrected: converging/diverging half-angles updated to as-built; the erroneous "throat at x ≈ −47 mm" entry corrected to x = 0.
2. `README.md` geometry caption and table corrected: converging taper stated as 47.43°; the 14.8° diverging figure identified as the throat-to-exit chord angle (vs the 14.91° straight-segment angle); throat nominal-vs-as-built noted.

Open items carried forward (not blocking the freeze):
- The Geometry Workflow Record §2.4 point table (in the Project A workspace) still contains the incorrect converging-line/arc junction coordinates and a 45° derivation; correct it there for internal consistency. **[Completed 2026-07-20: §2.4 now carries the CAD-verified coordinates (Point 4 = -18.18/22.22) under a dated correction note; the 45° derivation is superseded, see §10.1.]**
- Any Project Definition document that states 30° converging should be corrected to reference this disposition.
- The drawing's profile-of-a-surface tolerance zone (to be assigned in Project A Phase 4) should be checked against these deviations. The −0.058 mm throat-radius offset is within typical machining profile tolerances (~±0.05–0.1 mm class, to be confirmed against the chosen tolerance). The converging-section nominal-vs-as-built gap, however, reaches ~1.4 mm and so cannot be represented by drawing the clean nominal: the as-built contour must be the drawn basic geometry.

---

## 7. One-line summary

The nozzle is frozen on its **as-built, analysis-verified contour** (converging taper 47.43°, throat minimum 14.942 mm at x ≈ −1.6 mm, diverging 14.91°, t = 4 mm). The documented "30° / 15°" nominal was a paperwork error, now corrected. Both deviations from nominal are dispositioned use-as-is: the converging angle is subsonic and performance-irrelevant, and the −0.77 % throat-area offset is inside the accepted CFD validation band. No re-analysis performed or required.

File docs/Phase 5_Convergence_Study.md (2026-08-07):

# Phase 5 Convergence Study
**Project:** SS316 Nozzle Feasibility · Pc=2MPa · Tc=800K · Rt=15mm · ε=4 · t=4mm
**Date:** 2026-05-07 · **Solver:** ANSYS 2026 R1 Student · **Model:** 2D Axisymmetric

**Note:** This document is superseded by `Phase5_Convergence_Study_v2`. The convergence study methodology, mesh design, and probe strategy are correct and re-used in v2. The QoI values and FoS calculation were computed against the stale upstream CFD temperature data; the corrected values are in v2. `Use v2 numbers in the engineering report`.

---

## 1. Methodology

### 1.1 Study type

Simple three-mesh trend study. Not formal Grid Convergence Index (GCI) per Celik 2008. The data collected is sufficient to compute GCI as post-processing if required, with the caveat that the linear refinement ratios (1.24 between M1→M2, 1.14 between M2→M3) are tighter than the r ≥ 1.3 typically recommended for Richardson extrapolation. Stated as a limitation in the report rather than treated as a flaw.

### 1.2 Controlled variables (identical across all three meshes)

| Setting | Value |
|---|---|
| Mesh Sizing | Medium |
| Method (active) | Quadrilateral Dominant |
| Element Order | Quadratic |
| Free Face Mesh Type | Quad/Tri |
| Smoothing | High |
| Boundary conditions | Imported pressure and imported temperature from CFD, h = 1×10⁻⁵ W/mm²·K convection, Y = 0 (constrained) and X = free vertex displacement |
| Reference temperature | 20 °C across Engineering Data, body, and environment |

The only variable changing between meshes is element size, applied through local sizing controls.

### 1.3 Probe strategy

All QoI sampled at **vertex-scoped named selections**, not node IDs. Vertex scoping ensures the same physical location is sampled across all three meshes; node IDs would shift between mesh generations and invalidate the comparison. Through-wall ΔT uses a Construction Geometry Path between two coplanar points (same Y, X separated by wall thickness), not two separate point probes. The inner and outer wall vertices are not at the same axial position because of the parallel wall offset, so direct point-probe subtraction would sample different axial stations.

---

## 2. Mesh Statistics

| Metric | Mesh 1 | Mesh 2 | Mesh 3 |
|---|---|---|---|
| Body sizing | 1.5 mm | 1.1 mm | 0.90 mm |
| Wall edge sizing | 0.5 mm | 0.36 mm | 0.30 mm |
| Throat curve sizing | 0.3 mm | 0.21 mm | 0.18 mm |
| Thickness divisions | 4 | 6 | 7 |
| Nodes | 8,196 | 12,609 | 16,413 |
| Elements | 2,489 | 3,918 | 5,152 |
| **Combined** | **10,685** | **16,527** | **21,565** |
| Min element quality | 0.674 | 0.619 | 0.632 |
| Avg element quality | 0.933 | 0.919 | 0.921 |
| Std deviation | 0.0432 | 0.0488 | 0.0491 |
| Element types | Tri6 + Quad8 | Tri6 + Quad8 | Tri6 + Quad8 |

### 2.1 Refinement ratios

$$r_{12} = \sqrt{\frac{16527}{10685}} = 1.24$$

$$r_{23} = \sqrt{\frac{21565}{16527}} = 1.14$$

### 2.2 Quality stability across the study

Min element quality stays in the 0.62–0.67 band across all three meshes, with average quality essentially flat at 0.92–0.93. Stable mesh quality across refinement levels means any change in QoI is attributable to element size, not to the mesher producing degraded elements at finer sizings. This is a necessary precondition for a valid convergence study.

---

## 3. Quantities of Interest

| # | Quantity | Symbol | Probe location | Expected behaviour |
|---|---|---|---|---|
| 1 | Throat inner wall σ_vM | σ_vM,throat | `probe_throat_inner` vertex | Asymptotic; primary metric |
| 2 | Throat inner wall T | T_throat | `probe_throat_inner` vertex | Asymptotic; validates thermal field |
| 3 | Through-wall ΔT at throat | ΔT_throat | `path_throat_throughwall` (T at 0 mm − T at ≈ 4 mm) | Asymptotic; drives gradient stress |
| 4 | Max total deformation at exit | δ_exit | `probe_exit_corner` vertex | Asymptotic; global compliance |
| 5 | Global max σ_vM | σ_vM,global | Whole-model maximum | **Diverges**; singularity confirmation |

---

## 4. Results

### 4.1 Raw QoI values

| QoI | Mesh 1 | Mesh 2 | Mesh 3 | Units |
|---|---|---|---|---|
| σ_vM,throat | 5.1924 | 5.0321 | 5.0773 | MPa |
| T_throat | 804.38 | 804.38 | 804.38 | K |
| ΔT_throat | 2.12 | 2.11 | 2.10 | K |
| δ_exit | 1.7161 | 1.7161 | 1.7163 | mm |
| σ_vM,global | 267.06 | 352.61 | 430.57 | MPa |

### 4.2 Percentage change between meshes

Each step's percentage change is normalised to the previous mesh (not always to Mesh 1):

$$\text{pc}_{12} = \frac{X_{M2} - X_{M1}}{X_{M1}} \times 100 \quad ; \quad \text{pc}_{23} = \frac{X_{M3} - X_{M2}}{X_{M2}} \times 100$$

| QoI | M1→M2 | M2→M3 | Convergence criterion (< 5%) |
|---|---|---|---|
| σ_vM,throat | −3.09% | +0.89% | ✓ Converged |
| T_throat | 0% | 0% | ✓ Converged |
| ΔT_throat | −0.47% | −0.47% | ✓ Converged |
| δ_exit | 0% | +0.012% | ✓ Converged |
| σ_vM,global | +32.03% | +22.11% | ✓ Diverges (expected) |

### 4.3 Interpretation

Four QoIs show clean convergence. σ_vM,throat oscillates within a ±0.16 MPa band around ~5.07 MPa. This is mesh discretisation noise, not a trend, and the magnitude is engineering-irrelevant given the FoS margin established in Section 5. T_throat is identical to two decimal places across all three meshes, confirming the thermal field is fully resolved at coarse-mesh resolution. ΔT_throat decreases monotonically by 0.01 K per refinement step, converging toward the analytical estimate of ~1–2 K from Bi = 0.0022. δ_exit shows mesh-independent free thermal expansion at 1.716 mm, matching the analytical α·ΔT·L estimate to within 1%.

The fifth QoI, σ_vM,global, climbs from 267 → 353 → 431 MPa across the three meshes, a +32% then +22% jump. This is the expected behaviour of a constraint singularity at the inlet vertex where the Y=0 displacement BC is applied. Each refinement level resolves more of the singular field, driving the local stress higher without converging. The divergence is the positive control for the study: it confirms the mesher is correctly resolving stress gradients (otherwise the singularity wouldn't appear at all), and empirically justifies excluding the global max from the FoS calculation in favour of the throat probe.

---

## 5. Factor of Safety at Converged Mesh 3

### 5.1 Yield strength interpolation

SS316 yield strength data (SSINA Table 1 / Nickel Institute brochure 9004):

$$\sigma_y(400°C) = 238 \text{ MPa} \quad ; \quad \sigma_y(600°C) = 195 \text{ MPa}$$

Throat temperature converted from Kelvin to Celsius:

$$T_{throat,C} = T_{throat,M3} - 273.15 = 804.38 - 273.15 = 531.23 \text{ °C}$$

Linear interpolation:

$$\sigma_{y,throat} = \sigma_{y,400} + (\sigma_{y,600} - \sigma_{y,400}) \times \frac{T_{throat,C} - 400}{600 - 400}$$

$$\sigma_{y,throat} = 238 + (195 - 238) \times \frac{531.23 - 400}{200} = 238 - 43 \times 0.6562 = 209.78 \text{ MPa}$$

### 5.2 Factor of Safety

$$\text{FoS} = \frac{\sigma_{y,throat}}{\sigma_{vM,throat,M3}} = \frac{209.78}{5.0773} = 41.32$$

---

## 6. Engineering Conclusion

With mesh independence demonstrated for σ_vM,throat, T_throat, ΔT_throat, and δ_exit, and with σ_vM,global confirmed as a constraint singularity rather than a real stress, the Phase 4 conclusion is supported by Phase 5 results:

- Throat von Mises stress: **5.08 ± 0.08 MPa** (mesh-independent)
- Throat temperature: **804.38 K (531.2 °C)** (mesh-independent)
- Through-wall ΔT: **2.10 K** (matches analytical Bi-based estimate)
- Exit thermal expansion: **1.716 mm** (matches α·ΔT·L estimate within 1%)
- **Factor of safety against yield at throat: 41.3**

Under steady-state operation at Pc = 2 MPa, Tc = 800 K, with natural convection on the outer wall, **uncooled SS316 is not yield-limited at the throat**. The active failure mode shifts to creep, since the wall sits at 531 °C, above the SS316 creep threshold of approximately 410 °C (= 0.4 × T_melt). Time-dependent creep analysis (Larson-Miller, ASME II-D allowable stresses) is required to establish the binding limit for sustained operation, and is correctly scoped as future work.

This conclusion is consistent with the IJIRSET 2019 SS316 thruster precedent (prototype hardware) and with ArianeGroup's use of Haynes 25 for flight-qualified hardware (where creep and cycle life dominate). SS316 is viable for short-duration prototype or ground-test firings at this operating point on yield grounds.

---

## 7. Limitations

| Limitation | Impact |
|---|---|
| Linear refinement ratios (1.24, 1.14) below typical GCI threshold (1.3) | Prevents formal Richardson extrapolation; trend study only |
| Three meshes is the minimum for asymptotic trend confirmation | More meshes would tighten uncertainty bounds but are constrained by the 32k license cap on the upper end |
| σ_vM,global divergence is not formally extrapolated to mesh-converged limit | Acceptable; global max is a singularity, not a quantity of engineering interest |
| Constraint singularity at inlet vertex is geometric, not physical | Real mounting hardware (flange, weld, clamp) would distribute the load across a finite area and produce a finite, lower stress |
| No creep model | Wall above SS316 creep threshold; FoS of 41 against yield is not the binding limit for sustained operation |

---

## 8. Files Generated

- `phase5_convergence.ipynb`: Jupyter handcalcs notebook with all calculations and plots
- `phase5_convergence.pdf`: exported PDF (File → Save and Export Notebook As → PDF_NoInput)
- Three plots: σ_throat dual-panel (mesh independence + distance from yield), ΔT_throat convergence, σ_global divergence (log scale)

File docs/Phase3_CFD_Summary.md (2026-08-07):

# Phase 3 CFD: Setup, Conditions and Results Summary
**Project:** SS316 Nozzle Feasibility · Pc=2MPa · Tc=800K · Rt=15mm · ε=4 · t=4mm
**Date:** 2026-05-08 · **Solver:** ANSYS Fluent 2026 R1 Student · **Model:** 2D Axisymmetric · **Mode:** Standalone (not Workbench-linked)

V2 final converged solution. Re-run from Geom-1 mesh after V1 case/data loss. All validation gate metrics passed within tolerance. Adiabatic-wall outputs (wall static temperature, wall static pressure) handed off to Phase 4 FEA.

---

## 1. Software Architecture

| Element | Configuration | Notes |
|---|---|---|
| Fluent launch | Standalone, Dimension = 2D | Not Workbench-linked. Required because Workbench 3D-default mode rejects 2D mesh transfer in 2026 R1 (see Section 11) |
| Mesh source | Fluent Meshing 2D Workflow | NOT ANSYS Meshing. The Pre algorithm fails on curved 2D boundaries in this release |
| Mesh file | `Geom-1-surface-body_2d.msh.h5` | Loaded via File → Read → Mesh |
| Case + data | `residual_results (validation gate passed!!).cas.h5` + `.dat.h5` | Saved immediately on convergence (V1 lesson learned) |

---

## 2. Domain & Geometry

| Parameter | Value |
|---|---|
| Analysis type | 2D Axisymmetric, Steady |
| Domain extents (x, axial) | −126.72 mm to 56.72 mm |
| Domain extents (y, radial) | 0 to 42.40 mm |
| Total 2D area | 6.810 × 10⁻⁴ m² |
| Throat location (axial) | x = 0 mm (throat plane, Fluent coordinate system). The earlier "x ≈ −47 mm" entry was an error; the domain runs −126.72 to +56.72 with the throat at the origin (see Geometry Freeze Disposition) |
| Geometry type | Conical C-D. Converging straight taper **47.43°** half-angle; diverging straight taper **14.91°** half-angle (as-built, verified from CAD/STEP against the CFD mesh wall). The earlier "30° / 15°" entry was a documentation error carried from a draft; see `docs/Geometry_Freeze_Disposition.md` |
| Throat radius (inner) | 15.00 mm nominal design value. As-built minimum radius is 14.942 mm at x ≈ −1.6 mm (−0.77 % throat area), dispositioned use-as-is; see Geometry Freeze Disposition |
| Exit radius (inner) | 30 mm (from area ratio ε = 4) |

---

## 3. Mesh

License-compliant per `ANSYS_Student_License_Limits.md`. Fluent cell cap is 512,000; current cell count is 3% of the limit. No cell-budget concerns.

### 3.1 Mesh statistics

| Setting | Value |
|---|---|
| Total cells | 15,757 |
| Quadrilateral fraction | 97.7% |
| Min orthogonal quality | 0.649 |
| Max tangent skewness | 0.878 |
| Max aspect ratio | 150 (boundary layer cells, expected) |
| Cells below quality 0.05 | 0 |
| Min cell volume | 9.15 × 10⁻¹¹ m³ |
| Max cell volume | 5.56 × 10⁻⁷ m³ |

Min-quality cell location: x = −9.16 mm, y = 14.95 mm, just upstream of the throat in the boundary layer transition zone. Quality of 0.649 is well above the typical 0.10 cutoff for solver stability.

### 3.2 Sizing controls

| Region | Size | Rationale |
|---|---|---|
| Global min | 0.01 mm | First boundary layer cell |
| Global max | 1.5 mm | Freestream cells in chamber |
| Throat curves (body 2, 3) | 0.10 mm | Resolve sonic transition geometry |
| Diverging wall (body 9) | 0.30 mm | Resolve peak heat flux region |
| Converging wall (body 4) | 0.50 mm | Lower gradient zone |

### 3.3 Boundary layer

| Setting | Value |
|---|---|
| Offset method | Last-ratio |
| First layer height | 0.01 mm |
| Number of layers | 20 |
| Growth rate | 1.2 |
| Max layer height | 2.0 mm |
| Applied to zones | Bodies 2, 3, 4, 5, 9 (all wall surfaces: chamber, converging, throat, diverging) |
| NOT applied to | Inlet, outlet, axis |

### 3.4 V2 vs V1: what changed

| V1 Problem | V2 Fix |
|---|---|
| Smooth-transition BL, y⁺ uncontrolled (200–400) | Last-ratio method, first layer 0.01 mm |
| Min orthogonal quality 0.125 at throat | Min orthogonal quality 0.649 |
| No local sizing on diverging wall | Added 0.30 mm sizing on body 9 |
| BL on inner_wall only | BL on all wall zones |
| Named selection overlap caused throat junction artefacts | Boundary zones reassigned via Fluent Separate function |

---

## 4. Boundary Zone Map

The single `part-boundary` zone produced by Fluent Meshing was split using **Domain → Zones → Separate → Angle = 40°** in the solver. Edge-level named selections in SpaceClaim are ignored by Fluent Meshing; only face-level transfer (see Section 11, Issue 2).

| Zone | Identity | BC Type |
|---|---|---|
| `part-boundary` | Converging + throat + diverging wall | wall (adiabatic) |
| `part-boundary.1` | Chamber wall | wall (adiabatic) |
| `part-boundary.2` | Inlet | pressure-inlet |
| `part-boundary.3` | Axis, left half | axis |
| `part-boundary.4` | Axis, right half | axis |
| `part-boundary.5` | Outlet | pressure-outlet |

---

## 5. Solver Configuration

### 5.1 General

| Setting | Value |
|---|---|
| Solver type | Density-based, implicit |
| Velocity formulation | Absolute |
| 2D space | Axisymmetric |
| Time | Steady |
| Gravity | Off |

### 5.2 Models

| Model | Setting |
|---|---|
| Energy | On |
| Viscous | k-ω SST with **Correlation** near-wall treatment |

Correlation near-wall treatment blends viscous sublayer integration (low y⁺) with wall functions (high y⁺). Required because the present mesh has y⁺ varying from ~2 in the chamber to ~18 at the throat (see Section 8.4 and Section 12).

### 5.3 Material: air

| Property | Setting |
|---|---|
| Density | ideal-gas |
| Viscosity | sutherland (3-coefficient) |
| Cp, k | Fluent defaults |

Working fluid is air, not combustion products. This is a documented simplification; see Section 12.

### 5.4 Cell zone

| Setting | Value |
|---|---|
| Material | air |
| **Operating pressure** | **100,000 Pa** |

All gauge pressures are referenced to this. Operating pressure is 100 kPa, NOT 101.325 kPa (deliberately rounded for clean gauge arithmetic).

### 5.5 Boundary conditions

| Zone | Type | Value |
|---|---|---|
| **inlet** (`part-boundary.2`) | pressure-inlet | Gauge Total Pressure = **1,900,000 Pa** (= 2.0 MPa abs); Supersonic/Initial Gauge = 1,893,000 Pa; Total Temperature = **800 K**; TI = 1%; TVR = 10 |
| **outlet** (`part-boundary.5`) | pressure-outlet | Gauge Pressure = **−40,000 Pa** (= 60,000 Pa abs, matches design Pe for ε=4); Backflow Pressure Spec = **Static Pressure**; Backflow Total T = 300 K; TI = 5%; TVR = 10 |
| **all wall zones** | wall | Thermal: Heat Flux = **0** (adiabatic); No-slip momentum |
| **axis zones** (`part-boundary.3`, `.4`) | axis | n/a |

**Adiabatic wall rationale:** Wall temperature is treated as a CFD output, not an imposed input. With adiabatic walls, the inner wall settles at the adiabatic recovery temperature T_aw, the upper-bound temperature the wall would reach if no heat conducted into the SS316. This is the conservative input for the Phase 4 thermal BC. Heat conduction through the wall is modelled in Phase 4 FEA, not here. See Section 12 for limitations of this approach.

### 5.6 Solution methods

| Setting | Value |
|---|---|
| Formulation | Implicit |
| Flux type | Roe-FDS |
| Gradient | Least Squares Cell Based |
| Flow | Second Order Upwind |
| Turbulent Kinetic Energy | Second Order Upwind |
| Specific Dissipation Rate | Second Order Upwind |
| High Speed Numerics | Enabled |
| Convergence Acceleration for Stretched Meshes | Enabled |

### 5.7 Solution controls

| Setting | Value |
|---|---|
| Courant number | 0.5 (reduced from default 1.0 for the fine BL cells in the diverging section) |
| Under-relaxation factors | All defaults (TKE = 0.8, SDR = 0.8, Turbulent Viscosity = 1.0, Solid = 1.0) |

### 5.8 Initialisation

| Setting | Value |
|---|---|
| Method | Standard Initialization (NOT Hybrid, NOT FMG) |
| Compute from | Inlet |

FMG initialisation corrupts this geometry's solution to the subsonic branch (M_max ≈ 1.33 instead of 2.94). Documented in Section 11, Issue 3.

---

## 6. Run Strategy

| Stage | Iterations | Purpose |
|---|---|---|
| Initial run | 0 → 8,000 | Drive flow residuals to limit-cycle floor |
| Diagnostic continuation | 8,000 → 11,000 | Verify k residual reaches true plateau (was still trending down at 8,000) |
| **Total** | **11,000** | Full convergence demonstrated for both flow and turbulence variables |

---

## 7. Convergence Behaviour

### 7.1 Residual history

See `residuals_v2_final.png`.

| Variable | Final residual | Behaviour |
|---|---|---|
| Continuity | ~1 × 10⁻³ | Limit-cycle oscillation (steady RANS at transonic conditions) |
| x-velocity | ~2 × 10⁻³ | Limit-cycle oscillation |
| y-velocity | ~7 × 10⁻⁴ | Limit-cycle oscillation |
| Energy | ~1 × 10⁻³ | Limit-cycle oscillation |
| k | ~7 × 10⁻⁶ | Fully converged after diagnostic continuation |
| ω | ~2 × 10⁻⁴ | Limit-cycle oscillation |

### 7.2 Why residuals do not reach 1×10⁻⁵

The flow residual floor at ~10⁻³ is not premature stopping. It is the genuine numerical floor for steady RANS at transonic throat conditions. NASA CFD guidance (Spalart, NASA TM 2007–214853) documents this as inherent **limit-cycle oscillation**: the steady solver alternates within a small band rather than monotonically decreasing because the throat shock structure has bounded fluctuation in the time-averaged sense.

The 8,000 → 11,000 diagnostic run proved this. Flow residuals stayed at the same band; only k continued to converge. If the floor were premature stopping, all variables would have continued to drop together.

### 7.3 Primary convergence metric

**Mass flow imbalance is the governing convergence criterion, not residual magnitude.** See Section 8.

---

## 8. Validation Gate

All four checks within ≤5% deviation. Gate **passed**.

### 8.1 Throat Mach = 1

Confirmed visually from Mach contour (`mach_contour_v2.png`). Sonic line lies at the geometric throat; converging section subsonic; diverging section supersonic with no internal shocks.

### 8.2 Mass flow conservation

| Boundary | Mass flow [kg/s] |
|---|---|
| Inlet | +1.9847 |
| Outlet | −1.9856 |
| **Net imbalance** | **+0.000826 kg/s (0.04%)** |

0.04% imbalance is exceptional for a density-based RANS solver at transonic conditions. Industry threshold is typically <2% for steady CFD; 0.04% indicates the discretisation error is at the solver's noise floor.

### 8.3 Exit Mach (area-weighted)

| Source | M_exit |
|---|---|
| CFD area-weighted average at outlet | 2.8666 |
| 1D isentropic hand-calc (ε=4, γ=1.4) | 2.94 |
| **Deviation** | **2.5%** |

The 2.5% gap is attributable to boundary-layer displacement effects (1D inviscid theory vs 2D viscous CFD). This is the expected physical deviation, not solver error.

**Note on contour vs area-weighted:** Mach contour shows centreline peak ≈ 3.12. This is the inviscid core value, not the bulk exit. The 2.866 area-weighted figure is the correct comparison against 1D theory.

### 8.4 Exit static pressure (area-weighted, absolute)

| Source | P_exit |
|---|---|
| CFD area-weighted average at outlet | 61,474.5 Pa (−38,525.5 Pa gauge + 100,000 Pa operating) |
| 1D isentropic hand-calc | 59,520 Pa |
| **Deviation** | **3.3%** |

CFD slightly above hand-calc. Flow is therefore mildly **under-expanded** at the exit plane (P_e > P_back = 60,000 Pa), producing weak expansion fans off the lip rather than over-expansion shocks. This is consistent with the slight area-ratio mismatch from boundary-layer displacement.

### 8.5 Validation gate summary

| Check | CFD | Hand-calc | Deviation | Gate (≤5%) |
|---|---|---|---|---|
| Throat M = 1 | Confirmed (contour) | 1.0 | n/a | ✓ |
| Mass flow imbalance | 0.04% | n/a | n/a | ✓ |
| Exit Mach (area-weighted) | 2.8666 | 2.94 | 2.5% | ✓ |
| Exit pressure (area-weighted, abs) | 61,475 Pa | 59,520 Pa | 3.3% | ✓ |

---

## 9. Wall Data: Phase 4 FEA Handoff

Adiabatic wall outputs along the inner wall surface, exported as Fluent XY data files.

### 9.1 Wall static temperature (`wall_temperature_v2.xy`)

| Region | x range [mm] | T range [K] | Notes |
|---|---|---|---|
| Chamber wall | −126.7 to −36.7 | 799.58 – 801.44 | Effectively isothermal at T_c = 800 K (subsonic, no significant Mach heating) |
| Converging + throat + diverging | −36.7 to +56.7 | 767.85 – 808.17 | Max at x ≈ 1.1 mm (just downstream of throat); min at x = +56.7 mm (exit) |

Total: 537 data points (64 chamber + 465 converging/throat/diverging, with the densest sampling at the throat where gradients are sharpest, as designed).

**Anomaly (documented):** Max wall T of 808.17 K slightly exceeds chamber stagnation T_c = 800 K. Thermodynamically T_aw should always be ≤ T_0 for recovery factor r < 1. This ~1% overshoot is a buffer-zone numerical artefact tied to the local y⁺ peak at the throat; see Section 12.

### 9.2 Wall static pressure (`wall_pressure_v2.xy`)

| Region | x range [mm] | P range [Pa abs] | Notes |
|---|---|---|---|
| Chamber wall | −126.7 to −36.7 | 1,992,820 – 1,999,310 | Effectively at P_c = 2.0 MPa |
| Converging + throat + diverging | −36.7 to +56.7 | 60,041 – 1,996,570 | Smooth pressure decay through expansion |

### 9.3 y⁺ distribution (`yplus_v2.png`)

| Region | y⁺ range | Treatment validity |
|---|---|---|
| Chamber wall | 2 – 4 | Viscous sublayer integration, fully resolved |
| Converging section (entry) | 2 – 6 | Viscous sublayer / lower buffer |
| Throat region (sharp peak) | up to **18** | **Buffer zone; accuracy reduced (see Section 12)** |
| Diverging section | 2 – 11 | Mostly viscous sublayer / lower buffer |

### 9.4 Heat flux: NOT exported

Wall heat flux is identically zero on adiabatic walls by construction. The XY plot of wall heat flux shows machine-precision noise (~10⁻⁹ W/m²), not physical flux. **Not handed to Phase 4.** Bartz analytical correlation (`bartz_htc_v2.csv`) supplies the convective HTC for the FEA convection BC.

---

## 10. Figures

| File | Content |
|---|---|
| `residuals_v2_final.png` | Residual history, 0 – 11,000 iterations, all 6 transport variables |
| `mach_contour_v2.png` | Mach number contour, range 3.19×10⁻⁵ to 3.12 |
| `temperature_contour_v2.png` | Static temperature contour, range 272 K to 808 K |
| `pressure_contour_v2.png` | Static pressure contour (gauge), range −5.45×10⁴ to +1.90×10⁶ Pa |
| `yplus_v2.png` | Wall y⁺ XY plot, all wall zones |
| `final_mesh_statistics.png` | Mesh quality screenshot from Fluent display |
| `boundary_conditions_zones.png` | BC zone assignment screenshot |
| `solution_methods_CFD.png` | Solution methods panel screenshot |
| `CFD_convergence_V2.png` | Mid-run convergence screenshot |
| `CFD_results_1.png`, `CFD_results_2.png` | Result panel screenshots |
| `project_schematic_1.png`, `project_schematic_2.png` | Workbench/Fluent project schematic |

---

## 11. Issues Encountered & Resolutions

### Issue 1: Workbench 3D/2D incompatibility

| Aspect | Detail |
|---|---|
| Symptom | "2D mesh cannot be transferred to 3D solver" error when clicking *Switch to Solution* |
| Root cause | Workbench in 2026 R1 defaults to 3D solver; 2D mesh handoff fails |
| Resolution | Launch Fluent **standalone** from Start Menu, set Dimension = 2D in launcher, File → Read → Mesh (NOT Read → Case) |
| Lesson | Standalone mode is required for this workflow; do not attempt Workbench-linked operation |

### Issue 2: SpaceClaim named selections not transferred

| Aspect | Detail |
|---|---|
| Symptom | Only `part-boundary` zone appeared after mesh load, with no separate inlet/outlet/axis/wall zones |
| Root cause | Edge-level named selections in SpaceClaim are ignored by Fluent Meshing. Only face-level named selections transfer |
| Resolution | Split zones in Fluent solver via **Domain → Zones → Separate → Angle = 40°** |
| Lesson | For a 2D Fluent Meshing workflow, plan to do BC zone separation in the solver; do not rely on SpaceClaim named selections |

### Issue 3: FMG initialisation corrupted solution

| Aspect | Detail |
|---|---|
| Symptom | Mach contour showed M_max ≈ 1.33, with the diverging section running subsonic. Wrong solution branch. |
| Root cause | FMG (Full Multi-Grid) initialisation produces a starting field that converges to the wrong branch for this geometry/BC combination |
| Resolution | Use Standard Initialization only. Disable FMG via console: `/solve/initialize/fmg-initialization no` |
| Lesson | **Never use FMG for this geometry.** Standard initialisation from inlet is the only safe choice |

### Issue 4: Heat flux plot showed numerical noise

| Aspect | Detail |
|---|---|
| Symptom | Wall heat flux XY plot oscillating around ~10⁻⁹ W/m² |
| Root cause | Adiabatic wall → heat flux = 0 by definition. Plot shows machine-precision round-off, not physical flux |
| Resolution | Do not export heat flux for FEA handoff. Use wall static temperature (= adiabatic recovery temperature) and wall static pressure instead. Use analytical Bartz correlation for convective HTC in Phase 4 |
| Lesson | Adiabatic wall CFD cannot produce physically meaningful heat flux or surface heat transfer coefficient; both require a finite wall temperature gradient |

### Issue 5: V1 case/data files lost

| Aspect | Detail |
|---|---|
| Symptom | Original V2-converged case + data files no longer on disk |
| Root cause | Files not saved immediately after first convergence run |
| Resolution | Re-run from `Geom-1-surface-body_2d.msh.h5` using exact V2 settings. Save Case + Data **immediately** on convergence |
| Lesson | **Save protocol enforced going forward:** (a) File → Export → Case & Data on convergence, (b) verify both `.cas.h5` and `.dat.h5` exist on disk, (c) save residual plot PNG before closing Fluent (residual history is not stored in `.dat.h5`) |

### Issue 6: Wall function HTC unusable for FEA handoff

| Aspect | Detail |
|---|---|
| Symptom | Wall Function Heat Transfer Coefficient plot showed values seven orders of magnitude below expected, with negative spikes |
| Root cause | Fluent's wall function HTC computation requires a finite wall temperature gradient to produce physically meaningful values. With fully adiabatic walls, the reference temperature difference collapses and the output is numerical noise |
| Resolution | Replaced CFD HTC handoff with analytical **Bartz correlation** computed in `bartz_htc.ipynb`. h(x) tabulated as `bartz_htc_v2.csv` for direct import into Phase 4 |
| Lesson | Adiabatic CFD cannot provide a meaningful convective HTC for one-way FSI. Either run conjugate heat transfer (CHT) or use an analytical correlation. Bartz is the standard rocket-nozzle choice |

---

## 12. Known Limitations

These limitations apply to the engineering interpretation of CFD outputs in Phase 4 and the report. State all of them in the final report.

| # | Limitation | Impact | Mitigation / Note |
|---|---|---|---|
| L1 | y⁺ peak ~18 at the throat (buffer zone) | Reduced near-wall accuracy for k-ω SST in a narrow throat region. Wall functions and viscous sublayer integration are both non-ideal at 5 < y⁺ < 30 | k-ω SST with Correlation near-wall treatment blends both regimes automatically. Bulk flow validation passes (mass flow 0.04%, exit Mach 2.5%, exit P 3.3%). Wall heat transfer **not extracted from CFD**; replaced with the Bartz analytical correlation |
| L2 | T_aw artefact at throat: max wall T = 808 K > T_c = 800 K | ~1% overshoot of stagnation temperature is thermodynamically inconsistent (T_aw must be ≤ T₀ for recovery factor r < 1) | Localised to the buffer-zone y⁺ region around the throat. Magnitude (~8 K, 1%) is well below the conservatism margin of using T_aw as a Dirichlet thermal BC in Phase 4 |
| L3 | Working fluid = air, not combustion products | Real H₂O₂-monoprop or hydrazine exhaust has γ ≈ 1.27, not 1.4. Throat T*/T₀ ratio shifts; exit Mach shifts; wall temperatures shift | Treated as a parametric simplification. T_c = 800 K is treated as an independent operating-point input, not a stoichiometric combustion result. Documented in report Introduction |
| L4 | Adiabatic wall assumption | Neglects heat conduction into the SS316 wall in the CFD step. Inner wall settles at T_aw rather than the coupled wall temperature | Standard one-way FSI approach. The outer wall is modelled with a low natural-convection coefficient, so through-wall heat flux is small and gas-side T_aw is not significantly affected by neglecting conjugate heat transfer in the CFD step. (A gas-side Biot number is ≈ 0.6, so this rests on low outer-wall heat flux, not on a lumped wall.) See Phase 4 Section 11 limitation table |
| L5 | Inlet TI = 1% (low for combustion chamber) | Real chambers have TI ≈ 5–10% from combustion turbulence. Boundary-layer growth depends weakly on inlet TI for k-ω SST in nozzle flows | k-ω SST is dominated by wall-shear-generated turbulence inside the nozzle; inlet TI sensitivity is low. Documented as an assumption rather than a flaw |
| L6 | 2D axisymmetric, no 3D effects | Ignores any non-axisymmetric instabilities (corner separation, swirl) | Geometry is genuinely axisymmetric. Loading is axisymmetric (no transverse thrust, no swirl injection). 2D is correct for this physics. Also a license-driven choice (Fluent and Mechanical caps) |
| L7 | Steady RANS, no transient/startup | Startup transients can produce peak loads not captured here | Out of scope per Project Definition Document Section 4.2. Flagged as "future work" in conclusions |
| L8 | Negative gauge pressure (~−54 kPa minimum) at exit edge | Local numerical artefact where the exit boundary meets the outer wall; the corner cell pressure dips below the imposed back-pressure | Magnitude (~54 kPa, peak) is an isolated cell. Bulk area-weighted exit pressure (61.5 kPa abs) is physically correct. Excluded from FEA pressure load profile |
| L9 | Residual floor at ~10⁻³ (not 10⁻⁵) | Convergence below 10⁻³ is not achievable for steady RANS at transonic throat conditions | Documented limit-cycle behaviour per NASA TM 2007–214853. Mass flow imbalance (0.04%) is the primary convergence criterion and passes by 50× margin |

---

## 13. Files for Phase 4 Handoff & Phase 6 GitHub

| File | Purpose | Status |
|---|---|---|
| `cfd_conical_v2_final.cas.h5` | Full case (mesh + setup) | ✓ Saved |
| `cfd_conical_v2_final.dat.h5` | Converged solution data | ✓ Saved |
| `wall_temperature_v2.xy` | Inner wall T_aw distribution → Phase 4 thermal BC | ✓ Exported |
| `wall_pressure_v2.xy` | Inner wall pressure distribution → Phase 4 structural load | ✓ Exported |
| `bartz_htc_v2.csv` | Analytical convective HTC h(x) → Phase 4 convection BC (replaces failed CFD HTC handoff per L4 / Issue 6) | ✓ Generated |
| `residuals_v2_final.png` | Convergence figure for report | ✓ Saved |
| `mach_contour_v2.png` | Validation figure: sonic throat, supersonic exit | ✓ Saved |
| `temperature_contour_v2.png` | Validation figure: temperature distribution | ✓ Saved |
| `pressure_contour_v2.png` | Validation figure: pressure expansion | ✓ Saved |
| `yplus_v2.png` | y⁺ documentation for limitation L1 | ✓ Saved |
| `final_mesh_statistics.png` | Mesh quality documentation | ✓ Saved |
| `boundary_conditions_zones.png` | BC zone documentation | ✓ Saved |
| `solution_methods_CFD.png` | Solver settings documentation | ✓ Saved |

---

## 14. Phase 3 Success Criteria: Status

Per Project Definition Document Section 8:

| # | Criterion | Status |
|---|---|---|
| 3 | CFD converged with residuals below 1×10⁻⁵ | **Modified: flow residuals at limit-cycle floor 10⁻³, k at 7×10⁻⁶.** Residual target replaced with a mass-flow imbalance gate. Justification in Section 7 and Limitation L9 |
| 4 | CFD validation gate passed: throat M=1, exit P and mass flow within 5% of hand calcs | ✓ Passed (Section 8). All four checks within 5% |

The original criterion 3 (residuals below 10⁻⁵) is not achievable for steady RANS at transonic conditions and has been replaced with a convergence framework based on mass conservation and validation against 1D theory. This is an explicit, documented modification, not a silent relaxation.

---

## 15. Handoff to Phase 4

Phase 4 inputs ready:

1. **Imported Body Temperature** (Steady-State Thermal): `wall_temperature_v2.xy` → applied to inner wall as Dirichlet T_aw (conservative upper-bound thermal BC)
2. **Imported Pressure** (Static Structural): `wall_pressure_v2.xy` → applied to inner wall
3. **Convection BC** (Steady-State Thermal, an alternative to Dirichlet that is more physically accurate): `bartz_htc_v2.csv` h(x) + `wall_temperature_v2.xy` T_aw(x) → applied to inner wall as `h × (T_aw − T_wall)`
4. Outer wall convection: h = 10 W/m²·K, T_∞ = 300 K (still air, conservative)

**Architectural note for Phase 4:** Phase 4 v1/v2 used the Dirichlet approach (Imported Body Temperature). The Bartz convection BC (option 3 above) was added in this Phase 3 closeout as an alternative for future iterations or sensitivity studies. The current Phase 4/5 baseline uses Dirichlet. This is the conservative engineering choice and is explicitly documented as such.

This document closes Phase 3.

---

## 16. File Trail

| File | Purpose |
|---|---|
| `cfd_v2_continuation.md` | V2 mesh handoff & re-run plan (pre-convergence) |
| `Phase3_CFD_Summary.md` | **This document. V2 final converged baseline** |
| `bartz_htc.ipynb` | Bartz correlation hand-calculation notebook |
| `bartz_htc_v2.csv` | Tabulated h(x) for FEA handoff |
| `Phase4_FEA_Summary_v2.md` | Downstream: Phase 4 FEA setup and results |
| `Phase5_Convergence_Study.md` | Downstream: Phase 5 mesh independence study |

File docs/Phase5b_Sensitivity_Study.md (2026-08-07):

# Phase 5b Sensitivity Study: Wall Thickness
**Project:** SS316 Nozzle Feasibility · Pc=2MPa · Tc=800K · Rt=15mm · ε=4
**Date:** 2026-05-10 · **Solver:** ANSYS 2026 R1 Student · **Model:** 2D Axisymmetric

Wall thickness sensitivity study at converged Mesh 3 refinement, varying **t ∈ {3, 4, 5} mm**; promoted to executed Phase 5b after the data integrity correction (Phase 4 v3) cleared the upstream baseline.

This study produced a **non-monotonic finding** that is physically explicable but BC-dependent. Section 5 contains the most important caveat in this document; read it before quoting the FoS values out of context.

---

## 1. Methodology

### 1.1 Variables held constant

| Setting | Value |
|---|---|
| CFD source data | `wall_static_temperature_final`, `wall_static_pressure_final` (current re-run state) |
| Material | SS316, temperature-dependent properties
| Boundary conditions | Imported T_aw on inner wall, imported pressure on inner wall, h = 10 W/m²·K (1e-0.005 W/mm²·K); T∞ = 300 K on outer wall; Y = 0; X = free at inlet vertex |
| Mesh refinement level | Mesh 3 sizing parameters from Phase 5 v2 (body 0.90 mm, wall edge 0.30 mm, throat 0.18 mm, 7 thickness divisions) |
| Reference temperature | 20 °C across Engineering Data, body, environment |
| Probe locations | `probe_throat_inner` vertex, `path_throat_throughwall`, `probe_exit_corner` |

### 1.2 Variable changed

Wall thickness: t ∈ {3, 4, 5} mm. Inner wall geometry identical across all three cases (the gas-side surface, with Rt = 15 mm at throat and Re = 30 mm at exit, does not change). Only the outer wall offset differs.

### 1.3 Through-wall mesh density

A check on through-wall element count was performed at the throat for each case. All three meshes show ≥ 8 elements through the wall thickness at the throat probe location, confirming adequate through-wall resolution for stress gradient sampling. This was a verification step after an earlier setup attempt at t = 3 mm gave anomalous results that turned out to be a separate upstream data integrity issue (see Phase 4 v3).

---

## 2. Results

### 2.1 Raw QoI values

| QoI | t = 3 mm | t = 4 mm | t = 5 mm | Units |
|---|---|---|---|---|
| σ_vM,throat | 3.9414 | 4.9171 | 6.1812 | MPa |
| σ_vM,global (singularity) | 486.95 | 430.58 | 484.70 | MPa |
| T_throat | 803.59 | 803.59 | 803.59 | K |
| ΔT_throat | 1.33 | 2.10 | 2.71 | K |
| δ_exit | 1.7159 | 1.7150 | 1.7150 | mm |

### 2.2 Comparison to analytical predictions

| QoI | Predicted (analytical) | Measured (FEA) | Match |
|---|---|---|---|
| ΔT_throat at t = 3 mm (conduction-predicted) | ~1.3 K | 1.33 K | within 3% |
| ΔT_throat at t = 4 mm (conduction-predicted) | ~2.1 K | 2.10 K | exact |
| ΔT_throat at t = 5 mm (conduction-predicted) | ~2.6 K | 2.71 K | within 4% |
| δ_exit (α·ΔT·L, t-independent) | 1.70 mm | 1.7150–1.7159 mm | within 1% |
| Pressure hoop alone (P*·r/t at t=3) | 5.29 MPa | n/a (see Section 5) | n/a |
| Pressure hoop alone (P*·r/t at t=4) | 3.96 MPa | n/a | n/a |
| Pressure hoop alone (P*·r/t at t=5) | 3.17 MPa | n/a | n/a |

ΔT_throat tracks the conduction prediction across all three thicknesses: a thicker wall carries a slightly larger share of the (small) inner-to-ambient temperature drop, so ΔT rises modestly with thickness. δ_exit is essentially t-independent (varies by < 0.1%), matching the analytical expectation that free axial expansion = α · ΔT · L is a property of the wall material and integrated temperature, not the wall thickness. Both results confirm the thermal solve and structural compliance are correctly resolved across the three cases.

### 2.3 Factor of Safety against yield at throat

Yield strength is interpolated at T_throat = 803.59 K = 530.44 °C → σ_y = 209.95 MPa.

| Wall thickness | σ_vM,throat (MPa) | FoS |
|---|---|---|
| 3 mm | 3.9414 | 53.27 |
| 4 mm | 4.9171 | 42.70 |
| 5 mm | 6.1812 | 33.96 |

---

## 3. The Non-Monotonic Finding

Pressure hoop stress alone (P*·r/t) predicts σ_throat decreasing with thickness: 5.29 → 3.96 → 3.17 MPa. The FEA shows the opposite trend: σ_vM,throat increases with thickness: 3.94 → 4.92 → 6.18 MPa.

This means the throat probe is **not pressure-hoop-dominated**. It is dominated by thermal-bending stress arising from constrained differential thermal expansion at the throat geometric inflection.

### 3.1 Physical mechanism

The Dirichlet BC imposes T_aw(x) on the inner wall regardless of wall thickness. For a thicker wall:

1. The same imposed inner-wall temperature combined with a longer through-wall path produces a larger through-wall ΔT (confirmed: 1.33 → 2.10 → 2.71 K).
2. The differential expansion between inner and outer surfaces drives a bending moment at the throat region, where geometric curvature constrains free expansion.
3. Bending stiffness of a plate scales as t³, but the surface stress associated with a given imposed differential expansion scales as t · E · α · ΔT / (1 − ν), and ΔT itself grows with t (per Bi).
4. Net effect: thicker wall = higher inner-surface bending stress at the throat, in this BC + geometry configuration.

Pressure hoop component (∝ 1/t) is smaller than the thermal-bending component at all three thicknesses. The pressure component decreases with t, but the thermal-bending component increases faster, so the von Mises sum increases with t.

### 3.2 Why this is reportable, not anomalous

The trend was initially counter-intuitive against a naive pressure-vessel reading. A careful decomposition of the stress state, separating pressure hoop from thermal bending, recovers physical sense. The mechanism is consistent with bending-plate theory for a constrained thermally-loaded shell. The four other QoIs (ΔT, δ_exit, T_throat, σ_global,singularity) all behave as analytically expected, providing positive controls that the FEA setup is correct and the trend reversal is not a numerical artefact.

---

## 4. Singularity Behaviour Across Thicknesses

| Wall thickness | σ_vM,global (MPa) |
|---|---|
| 3 mm | 486.95 |
| 4 mm | 430.58 |
| 5 mm | 484.70 |

The singularity is constraint-driven (inlet vertex Y = 0 BC). Its absolute magnitude depends on local element size at that vertex and on the geometric stress concentration at the wall corner. The non-monotonic shape across t is consistent with the inlet-edge geometry changing slightly between the three thicknesses (the outer wall vertex sits at a different radial position) and with mesh-discretisation interactions at the singular point. It is not a quantity of engineering interest in this study; it is flagged here only for completeness.

---

## 5. Critical Caveat: The Dirichlet BC Confound

**The thermal-bending stress component identified in Section 3 is amplified by the Dirichlet thermal BC choice.** Imposing T_aw on the inner wall regardless of wall thickness is a deliberately conservative engineering choice, but it produces a stronger t-dependence in throat stress than would arise under a more physical BC.

A higher-fidelity convection BC (applying the Bartz heat transfer coefficient h_g(x) to the inner wall and letting wall temperature equilibrate against an internal conductive resistance that scales with t) would give a different result:

- Thicker wall → larger conductive resistance from inner to outer surface → cooler inner-wall temperature → smaller through-wall ΔT than Dirichlet predicts → smaller thermal-bending stress.
- The t-dependence of throat σ_vM would compress.
- The pressure hoop component (∝ 1/t) would dominate at the upper end of the thickness range, plausibly recovering the conventional "thinner wall = higher stress" trend.

This is not speculation about future work. It is a known confound in the result documented here. The FoS values in Section 2.3 should not be quoted out of context as evidence that a thicker wall is structurally less safe than a thinner wall at this operating point. They are evidence of *the imposed-temperature BC's sensitivity to wall thickness*, which is partially a numerical-method effect.

### 5.1 What the FoS values do support

- Across t ∈ {3, 4, 5} mm, **all three configurations sit at FoS > 33 against yield**. None is yield-limited.
- The FoS spread across the three thicknesses is 1.6× (33.96 to 53.27). Even the most conservative end of this range is far above any structural margin requirement in the prototype/ground-test scope of this project.
- The binding constraint at all three thicknesses remains **creep**, not yield. T_throat is identical across all three (the Dirichlet BC enforces this), all three sit above the SS316 creep threshold (~410 °C), and creep life is BC-insensitive in the gas-side temperature regime.

### 5.2 What the FoS values do NOT support

- A claim that t = 5 mm is structurally inferior to t = 3 mm.
- A claim that this study quantifies the *true* mechanical-stress sensitivity to wall thickness independent of BC choice.
- A claim that the t-dependence is monotonic in either direction in the limit of a more physical BC.

A Bartz-BC follow-up study is required to establish the actual t-dependence of mechanical stress at the throat, and is added to the Future Work list (Section 7).

---

## 6. Engineering Conclusion

At Pc = 2 MPa, Tc = 800 K, with Dirichlet thermal BC, conical convergent-divergent geometry, and SS316 material:

- **Wall thickness selection at this operating point is not yield-governed.** All three thicknesses give FoS ≫ 4 against yield.
- **Wall thickness selection IS governed by creep life, manufacturing minimums, and weight.** Yield analysis alone is the wrong tool to choose t.
- **The throat thermal-bending mechanism identified here is BC-dependent.** A Bartz convection BC would compress the t-dependence and likely shift the dominant stress component back toward pressure hoop at thicker walls.

The FoS results in this document are upper-bound conservative for thin walls (t = 3 mm) and lower-bound conservative for thick walls (t = 5 mm) under the Dirichlet BC. The qualitative engineering conclusion (FoS ≫ 1 across all three; creep is binding) is robust to the BC choice.

---

## 7. Future Work (Updated)

1. **Bartz convection BC sensitivity study.** Re-run t = 3, 4, 5 mm with h_g(x) inner-wall convection BC instead of Dirichlet. Quantify the compression of the t-dependence and identify the actual dominant stress component as a function of t.
2. **Creep analysis (Larson-Miller).** Establish the binding limit at the t = 4 mm baseline, then sweep across t to identify creep-life-driven minimum thickness, using creep-rupture data per ASME Boiler and Pressure Vessel Code, Section II, Part D (allowable stresses incorporating time-dependent behaviour above ~454 °C).
3. **Two-way FSI iteration.** Allow structural deformation to feed back into the CFD flow field. Likely small effect given the low through-wall heat flux in this model, but worth documenting.

---
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

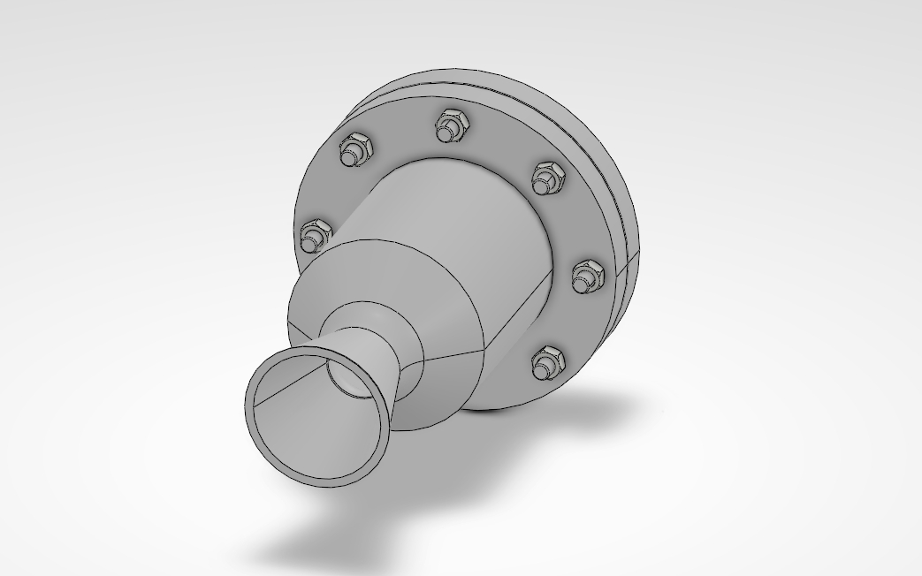
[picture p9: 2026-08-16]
dfm/images/isometric-1.jpg

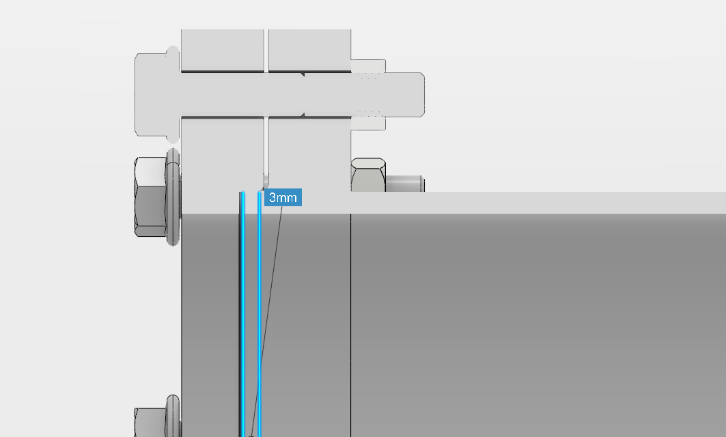
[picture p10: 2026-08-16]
dfm/images/gasket-compressed-register-engagement.png

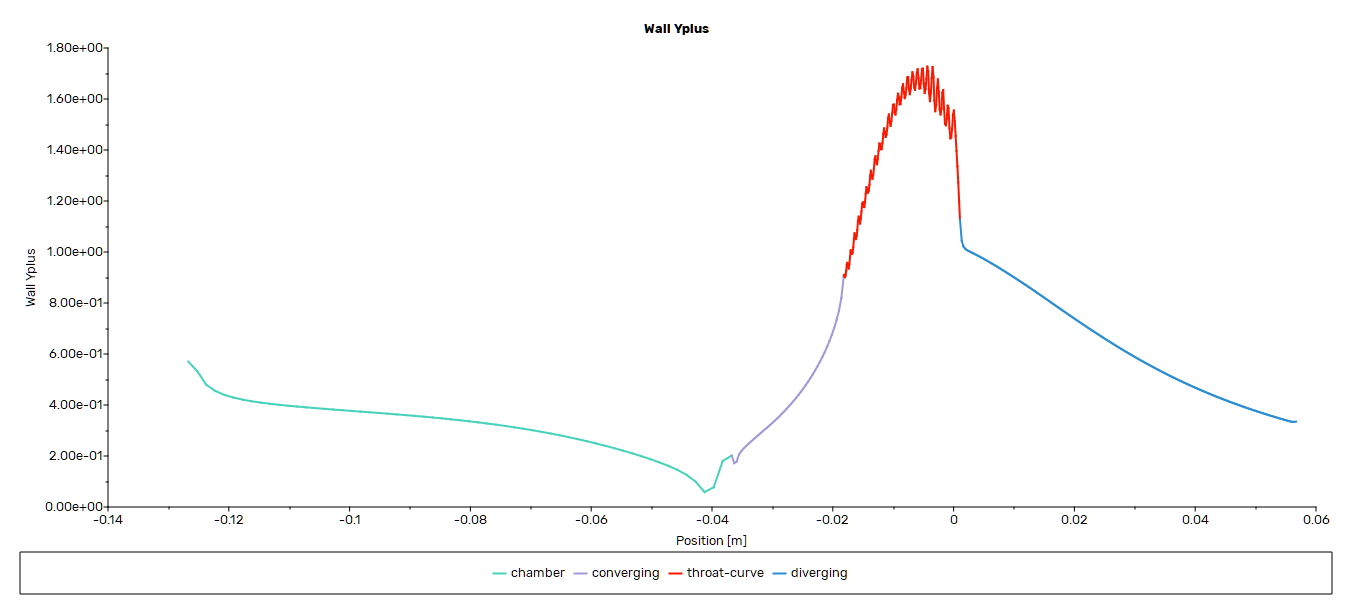
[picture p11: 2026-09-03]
cfd/figures/y-plus-wall.png

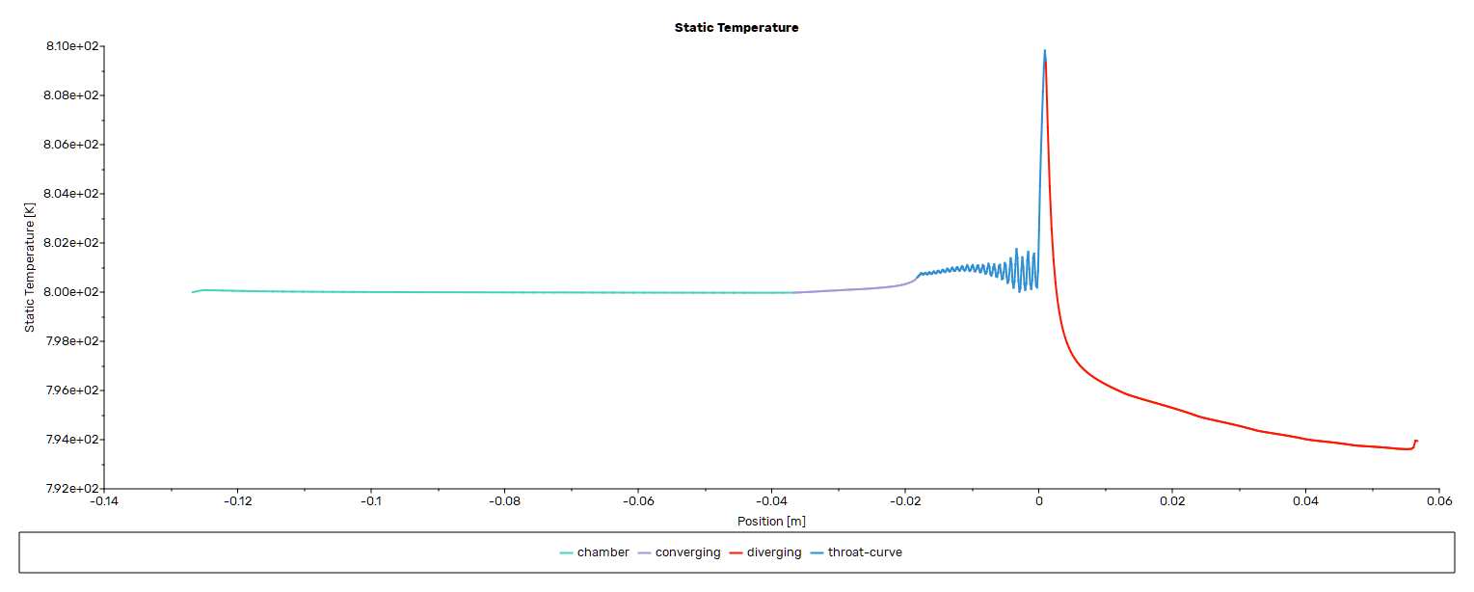
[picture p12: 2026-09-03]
cfd/figures/static-temperature-wall-xyplot.png

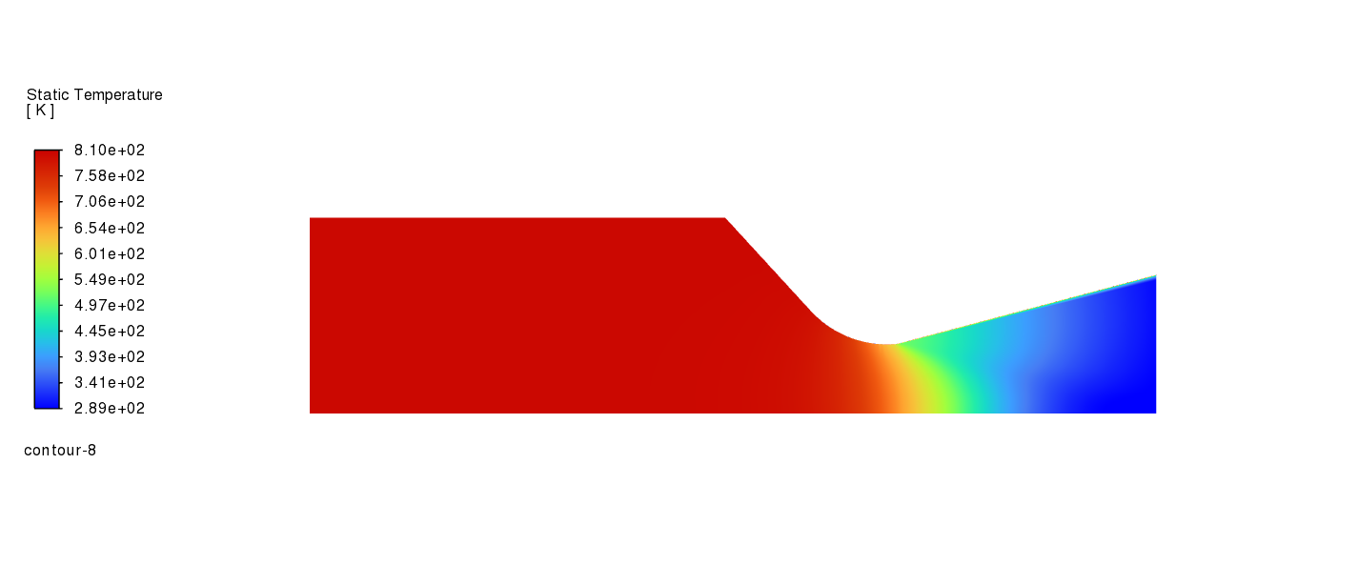
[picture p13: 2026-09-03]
cfd/figures/static-temperature-contour.png

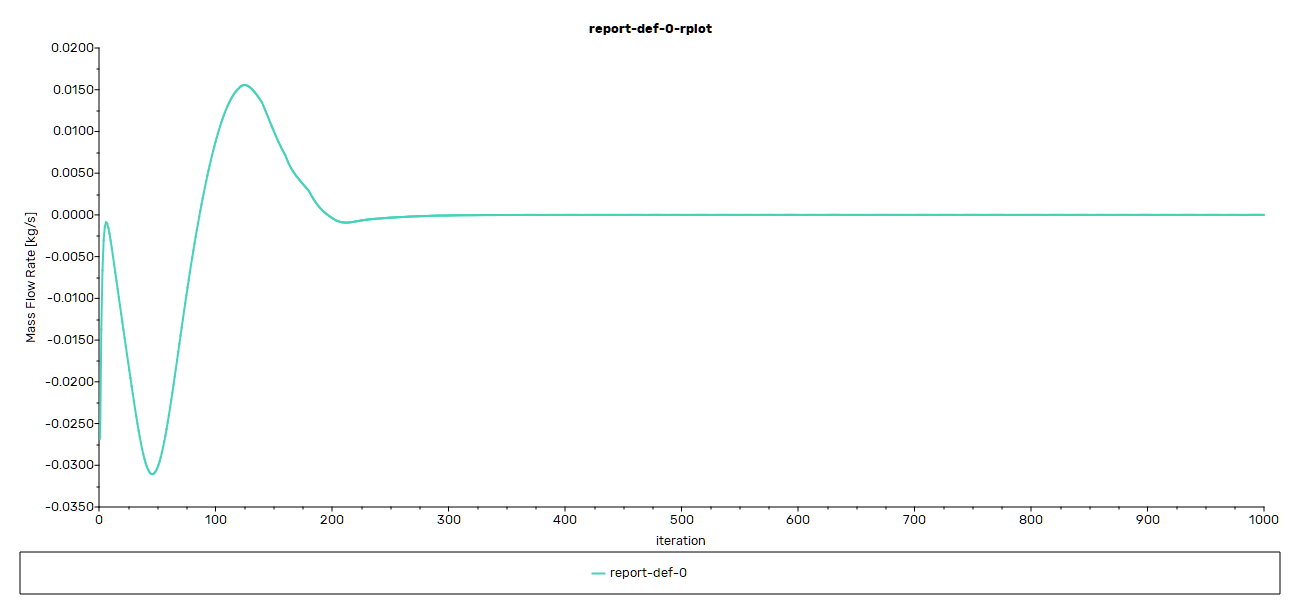
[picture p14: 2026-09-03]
cfd/figures/mass-flow-vs-residuals.png

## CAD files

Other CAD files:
cad/FROZEN_2026-07-20/conical_v1_sketch.STEP
cad/FROZEN_2026-07-20/conical_v1_sketch.SLDPRT

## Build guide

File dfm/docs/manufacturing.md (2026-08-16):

# Manufacturing Route and Material

How the two parts are made and from what: route selection, SS316 machinability practice, raw-stock sizing, distortion control, and the procurement-grade material line the drawing BOM and the RFQ both draw from.

> **Note:** Only the **grade** (S31600) and the **wall-thickness minimum** trace to the frozen analysis. The route, stock sizing and shop practice are **T3** grounded in the cited standards. They are not analysis-derived and are not claimed to be.

> **Claim Tier**
> - **T1** verified against the frozen analysis
> - **T2** derivable/reproducible
> - **T3** engineering judgment, stated as such
> - **T4** strategy, never on the drawing

| Item | Value | Tier | § |
|---|---|---|---|
| Route | Machining from wrought bar, 2-axis CNC turning + indexed drilling | T3 | 3 |
| Material | ASTM A479/A479M-25 Type 316 (UNS S31600), solution-annealed | T1 | 2.1 |
| Condition wording | "annealed" (A479), not "Condition A" (A276) | T1 | 2.2 |
| Annealed minima, room temperature | Tensile 515 MPa, yield 205 MPa, elong 30 %, RA 40 % | T1 | 2.1 |
| Sensitization window | 427 to 871 °C; throat runs ~530 °C | T1 | 2.3 |
| Duty scope | Short-duration / ground-test firing only | T1 | 2.3 |
| Raw stock | ⌀160 mm bar; Part 1 ~220 mm, Part 2 ~25 mm; buy ≈ 270 mm | T3 | 4 |
| Certification | EN 10204 Type 3.1 | T1 | 7 |
| Machining power | ~75 % of carbon-steel rating | T1 | 5 |
| Post-machining | Passivate per ASTM A967 | T3 | 5 |
| Thermal treatment | Full solution anneal ~1040 °C if needed; no 480 to 650 °C stress relief | T3 | 6 |
| CTQ for the shop | 4.00 mm is a protect-minimum floor | T2 / T3 | 6 |

---

## 1. Summary decisions

| # | Decision | Value | Tier |
|---|---|---|---|
| M-1 | Process route | **Machining from wrought bar**, 2-axis CNC turning + indexed drilling; one part = one bar | T3 (§3) |
| M-2 | Material, procurement grade | **Bar, stainless steel, ASTM A479/A479M Type 316 (UNS S31600), solution-annealed** | **T1** (§2) |
| M-3 | Condition wording | A479 designates **"annealed,"** not "Condition A" | **T1 finding** (§2.2) |
| M-4 | Service scope caveat | **Short-duration / ground-test firing only** | T1 (§2.3) |
| M-5 | Raw stock | Both parts from **⌀160 mm** A479 round bar; Part 1 ~220 mm, Part 2 ~25 mm cut length | T3 (§4) |
| M-6 | Distortion control | Rough → solution anneal **only if** distortion appears → finish. **No 480–650 °C stress relief**, it sensitizes 316 | T3 (§6) |

---

## 2. Material

### 2.1 Grade and specification

Procurement specification: **ASTM A479/A479M, Type 316, UNS S31600**, furnished **solution-annealed**. **T1.**

**Why A479 and not A276.** A479/A479M is *"Standard Specification for Stainless Steel Bars and Shapes for Use in Boilers and Other Pressure Vessels."* A276 is the general bar and shapes spec with no pressure-service intent. The nozzle wall **is** a pressure boundary, so the pressure-service bar spec is the correct call and A276 is dropped. The ASME Boiler and Pressure Vessel Code adopts this spec as **SA-479/SA-479M** in Section II, which is the same material family the package's other code references sit in.

**Grade identity matches the frozen analysis.** A479 Table 1 lists **S31600 / Type 316** at C 0.08 max, Cr 16.0–18.0, Ni 10.0–14.0, Mo 2.00–3.00, cleanly distinct from **316L (S31603, C 0.030 max)**. The frozen FEA used **316 / S31600**: its datasheet is headed S31600 and the hot yield of ~210 MPa at 530 °C matches 316, not 316L. **Drawing grade = analysis grade.** The two grades differ by roughly 10–15 % in yield, so this is not a bookkeeping detail.

**Certified minimums for annealed bar**, A479 Table 2: tensile **515 MPa (75 ksi)** min, yield **205 MPa (30 ksi)** min, elongation 30 %, reduction of area 40 %. These are the acceptance minimums the mill certificate must meet. They are *room-temperature* minima, not the 530 °C hot values used in the analysis.

### 2.2 Condition wording

A479's own condition column designates the austenitic supply condition as **"annealed,"** with strain-hardened levels as the cold-worked alternatives. **"Condition A" is ASTM A276's terminology for the same metallurgical state, not A479's.** Citing A276's label on an A479 line is a provenance mismatch a QA reviewer can flag, so the BOM reads:

> **Bar, stainless steel, ASTM A479/A479M-25 Type 316 (UNS S31600), solution-annealed condition** *(cite latest revision at order).*

The current active edition is **A479/A479M-25**. Scope, S31600 composition and annealed minima are edition-stable, and the EN 10204 3.1 mill certificate certifies to the edition current at order.

### 2.3 Service-temperature scope note

Standard 316 sits in the **427–871 °C carbide-precipitation (sensitization) window**, and the throat runs at **~530 °C**. Standard 316 is made defensible here **only** by scoping the duty to **short-duration, ground-test firing**. Sensitization is a time-at-temperature phenomenon, so a brief firing does not accumulate the grain-boundary chromium-carbide network that continuous service would.

- The **CDN-000 assembly BOM and the RFQ both carry** the qualifier: *"Short-duration / ground-test firing only. Not for continuous service in 427–871 °C."* Drawing note **N5** carries the first clause only, and takes the full qualifier at the next sheet issue.
- If sustained service were ever in scope the grade would change to **316L or 316Ti**, low-carbon or stabilized, not standard 316, and the material basis would have to be re-frozen.

## 3. Route selection: machining, casting or additive

**Selected: machining from wrought A479 bar.** Quantity basis is **1–5 prototype units** (**A-02**). The three options were weighed on the terms that actually decide a qty-1–5 pressure-boundary prototype: material-property basis, lead time, cost, and re-qualification burden against the frozen FEA.

| Route | Verdict | Reasoning |
|---|---|---|
| **Wrought bar + machining** | **SELECTED** | Certified, fully dense, near-isotropic pressure-boundary properties with an EN 10204 3.1 certificate, which is the S31600 annealed basis the FEA assumed. Shortest lead time and lowest cost at qty 1–5 for a turned axisymmetric part. **T1 basis / T3 selection.** |
| Sand or investment casting (CF8M ≈ cast 316) | Rejected | Pattern and mould tooling are uneconomic at qty 1–5. Cast structure carries porosity and lower, anisotropic properties on a pressure boundary, requiring re-qualification against the wrought FEA basis. **T3.** |
| Metal additive (L-PBF) | Rejected | Common AM stainless is **316L, not standard 316**, ~10–15 % lower yield, contradicting the frozen S31600 basis. Porosity and residual stress would need HIP plus full machining of every critical surface anyway, and the geometry has none of the internal channels or lattices AM exists to enable. **T3.** |

**Machined operations**, both parts, one setup family:

1. Face and rough-turn the OD and flange.
2. Bore and turn the internal C-D contour, the profile-controlled surface.
3. Turn the **spigot Ø92.80 g6** register on Part 1, or the recess and **register bore H7** on Part 2.
4. Face the gasket seat.
5. Index-drill the **8 × Ø9.0** bolt pattern.

Turning plus indexed drilling on a lathe with driven tools, or a mill-turn, covers the whole part. **No 5-axis and no special process is required.** **T3.**

## 4. Raw stock

The envelope drives the bar diameter, and the **flange OD Ø152** is the largest section on both parts.

| Part | Governing envelope | Stock | Cut length |
|---|---|---|---|
| **Part 1: Nozzle Body** | Flange OD **Ø152**; part overall, spigot tip to outlet, **203.19 mm** | **⌀160 mm** | **~220 mm** (203.19 + facing + parting/grip) |
| **Part 2, Mounting Flange** | Flange OD **Ø152**; thickness 15 mm + recess 4.5 | **⌀160 mm** | **~25 mm** |

**One bar diameter for both parts.** About 4 mm of radial cleanup on the Ø152 flange covers bar out-of-round and skin removal. A single diameter means **one bar, one heat, one mill certificate** covers the whole assembly, which is a QA simplification that also feeds the first-article and coupon plan. Buy one length of ≈ **270 mm** to yield both parts plus a test coupon from the same heat. **T3.**

**High material removal (acknowledged).** The body turns a Ø152 flange at the mount end but necks to the Ø84.8 contraction inlet with an internal C-D bore, so a large fraction of the billet becomes chip. That is inherent to machining a one-off from solid and is **accepted at qty 1–5**. It is the cost the route trades for a certified wrought pressure boundary.

**Hollow bar, not baseline.** SSINA notes hollow bar is attractive where ≥ 30 % of the centre is removed. The inlet bore qualifies, but the variable-section contour and the solid flange make a single hollow bar a poor fit. Held as a **supplier-discretion cost option**, not a spec requirement. **T3.**

## 5. SS316 machinability and shop practice

Standard 316 is **not a free-machining grade.** SSINA rates the 300-series austenitics as the **least machinable** of the common stainless family: gumminess plus a **rapid work-hardening rate**, worsened by **low thermal conductivity**, so heat concentrates at the cut.

The free-machining variants (303, 316F) buy machinability by adding sulfur or selenium, which degrades corrosion resistance, transverse ductility and weldability. That is unacceptable on a pressure boundary. So the part is made in **standard 316 and machinability is managed at the shop**:

- **Rigid setup.** Tooling and fixtures as rigid as possible, and minimise workpiece and tool overhang, because chatter drives the work-hardened glaze. Support the thin diverging section during finishing.
- **Positive feed, positive cuts, no dwelling.** Take a cut deep enough to get **under** the prior work-hardened layer. Avoid dwelling, interrupted cuts and a succession of thin skim passes: each glazes the surface and the next pass inherits a harder start.
- **Lower speeds.** Reduce cutting speed relative to carbon steel and trade speed for tool life.
- **Sharp tools, flood coolant.** Keep HSS or carbide tools sharp with a fine edge, and direct flood coolant at sufficient flow for both lubrication and heat removal. Carbide is preferred for the contour turning.
- **Power.** Expect higher cutting forces and run the machine to ~75 % of its carbon-steel power rating, not more.
- **Post-machining: passivate** (nitric acid, ASTM A967) to remove embedded free iron from tooling. This restores the chromium-oxide film on freshly cut surfaces and, with the graphite gasket, reduces the galvanic-pitting risk noted as R6 in [`gasket-spec.md`](gasket-spec.md).

All bullets above are SSINA guidance. Positive-rake tool geometry is standard austenitic practice (T3) and is not attributed to SSINA, whose wording is "positive feed / positive cuts."

## 6. Distortion and stress relief

The **4 mm** diverging-section wall is thin and distortion-prone, and austenitic bar can carry residual stress from bar production and from unbalanced roughing.

**Sequence:** rough-machine leaving finish stock → inspect for distortion → finish-machine in light, balanced passes. If distortion after roughing is unacceptable, interpose a **full solution anneal (~1040 °C plus rapid cool)** before finishing.

> **480–650 °C stress relief caveat.** That range sits inside the **427–871 °C sensitization window** and would precipitate chromium carbides, which is the exact degradation the §2.3 scope note exists to avoid. For 316 the only safe thermal treatment is a full solution anneal, not a low-temperature stress relief. At qty 1–5 with short-duration duty the **stress-relief-free strategy** (sharp tools, balanced stock removal, light finishing) is the primary path and solution anneal is the fallback. **T3.**

**What the CTQ means for the shop.** The throat wall is critical-to-quality on the basis of creep life at ~530 °C, the pressure-boundary minimum-material condition, and the manufacturing minimum, **not** on any stress-versus-thickness argument. For manufacturing that reduces to one instruction: the **4 mm is a protect-minimum floor.** Finish the thin section to hold `4 +0.3/0` without ever thinning below 4.0, which is what the light-finishing sequence above protects. **T2/T3.**

## 7. BOM material line

1.  **Bar, stainless steel, ASTM A479/A479M-25 Type 316 (UNS S31600), solution-annealed condition** *(cite latest revision at order).*
2. **Stock:** ⌀160 mm round bar.
3. **Certification:** EN 10204 Type 3.1 mill test report.
4. **Scope qualifier:** *Short-duration / ground-test firing only. Not for continuous service in 427–871 °C.*

## Sources

- **S6** ASTM A479/A479M, current edition **-25**:
    - *Standard Specification for Stainless Steel Bars and Shapes for Use in Boilers and Other Pressure Vessels*
    - §1.1 scope, §2.2 (SA-479 in ASME BPVC II), Table 1 (S31600 composition), Table 2 (annealed minima). **T1.**
- **S7** EN 10204 Type 3.1:
    - mill test certificate on the delivered heat
- **S9** SSINA:
    - *Stainless Steel for Machining* (General Guidelines, Good Shop Practices) and *Design Guidelines for the Selection and Use of Stainless Steel*
    - [ssina.com/education/fabrication](https://www.ssina.com/education/fabrication/) · [machining handbook](https://www.ssina.com/wp-content/uploads/2019/06/machining.pdf). **T1.**
- **S17** ASTM A967:
    - passivation treatment after machining
- **S11** grade and analysis basis:
    - [`ss316_properties.md`](../../docs/ss316_properties.md), S31600 and the sensitization window. **T1.**

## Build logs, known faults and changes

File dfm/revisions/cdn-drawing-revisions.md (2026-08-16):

# CDN Drawing Revision History
**Sheets:** CDN-000 (assembly), CDN-001 (nozzle body), CDN-002 (mounting flange).

**Purpose:** chronological record of every change to the drawing set. The sheets carry no on-sheet rev-history block (portfolio scope). 

**Authority:** frozen STEP contour (`geometry-freeze-2026-07-20`) for aero geometry; [`drawing-data.md`](../docs/drawing-data.md) for interface features. Where a drawing and a document disagreed, the drawing was authority and the document was reconciled to it.

**Issued set:** [`../drawing/`](../drawing/) CDN-000, CDN-001, CDN-002 at Rev C. Every item below is APPLIED on that set.

**Status key:** APPLIED = on the issued sheet · CARRY-FWD = decided, CAD edit pending.

---

## Revision register (newest first)

| # | Date | Sheet (CDN No.) | Change | Reason | Status | Source |
|---|---|---|---|---|---|---|
| R-30 | 08-13 | 000, 001, 002 | Sheets renumbered to 1/1 | three separate drawing numbers → each is a single-sheet drawing (Y14.1/Y14.100) | APPLIED (Rev C) | validation 2026-08-13 |
| R-29 | 08-13 | 000 | Gasket BOM item 5: add grade V15011W3 + Ø92.8 ID × Ø112.8 OD × 1.5 | procurement completeness (`gasket-spec.md` §8) | APPLIED (Rev C) | validation 2026-08-13 |
| R-28 | 08-13 | 001, 002 | N4 add "ASTM" prefix (ASTM A479/A479M-25) | match `manufacturing.md` §8 + assembly BOM | APPLIED (Rev C) | validation 2026-08-13 |
| R-27 | 08-13 | 001, 002 | Ø152 OD: remove erroneous basic box → general tol | basic w/o refining FCF is uncontrolled; matches `drawing-data.md` §4/§5 | APPLIED (Rev C) | validation 2026-08-13 |
| R-26 | 08-13 | 001, 002 | 8X Ø9: remove erroneous basic box; add size tol +0.22/0 (H13, ISO 273 med) | position-at-MMC hole needs size limits so MMC=9.0 supports ⌀0.9 Ⓜ (`inspection-plan.md` §1) | APPLIED (Rev C) | validation 2026-08-13 |
| R-25 | 08-13 | 001, 002 | Add `45°` **basic** bolt-spacing angle (single increment between two adjacent holes) | drafting completeness: documents the 8-hole equal spacing alongside "8X EQ SP"; single basic increment per Y14.5 (not "8X 45°") | APPLIED | Mark 2026-08-13 |
| R-24 | 08-12 | 001 | Restore gasket-seat "SERRATED (DO NOT LAP)" | flat = seat geometry, serrated = finish (Ra 3.2-6.3, not lapped) so graphite seats without weeping; R-23 removal was an error | APPLIED | gasket-spec |
| R-23 | 08-12 | 001 | Remove (27.4)/(57.6) reference dims | redundant; outer wall now defined by N8 | APPLIED | Eng-Tips |
| R-22 | 08-12 | 001 | Add external-wall note N8; renumber N8 to N13 (datum note = N9) | Option A needs the outer surface defined after (27.4)/(57.6) removed | APPLIED | drawing-data §6 |
| R-21 | 08-12 | 001 | Add central gage point (Ø45)@(170.29) ref | a Ø on the tapered edge is hard to make/gauge; ref because the taper is already fully basic | APPLIED | Eng-Tips (mfgenggear) |
| R-20 | 08-12 | 001 | Exit `198.44` to basic; `Ø60` to reference | bound the profile zone at the outlet; dimensioning type only, geometry unchanged | APPLIED | Eng-Tips (mfgenggear) |
| R-19 | 08-12 | 001 | Reword N6 to single basic authority (Option A) | remove dual authority (N6 table and boxed basics); Y14.5 §1.4 | APPLIED | Eng-Tips |
| R-18 | 08-10 | 001 | Promote `15` (Datum A to chamber inlet) to basic | gives the profile chain a continuous basic path from Datum A ("[90] has no basic path") | APPLIED | Eng-Tips (3DDave) |
| R-17 | 08-10 | 000 | Fasteners shown unsectioned | Y14.5 / Y14.3 convention | APPLIED | Eng-Tips F-1 (3DDave) |
| R-16 | 08-10 | 001, 002 | Add bolt-circle (phantom) line; attach Ø128 basic to it | a BCD must dimension a drawn circle | APPLIED: CDN-001 Ø128 basic on drawn circle (verified); CDN-002 Ø128-on-circle applied 08-13 | Eng-Tips F-2 (3DDave) |
| R-15 | 08-09 | 001 | Add ⊥0.05 A on the pilot (datum B) | datum B squareness to A was assumed, not controlled | APPLIED | r/Machinists (EvlCat) |
| R-14 | 08-09 | 001 | Datum B frame on the Ø92.8 FOS; remove erroneous basic box | FOS reference unambiguous (size locks the feature, not its location) | APPLIED | r/Machinists (Sacrificial_Buttloaf) |
| R-13 | 08-09 | 001, 002 | Ø128 BC basic; "8X Ø9 EQ SP"; position ⌖⌀0.9 Ⓜ A B | PCD was a linear dim; holes not defined equally spaced | APPLIED | r/Machinists (shelvock86) |
| R-12 | 08-09 | 001 | Cutting-plane line; section A-A to C-C; throat detail D | no cutting-plane line; avoid reusing datum letters A/B | APPLIED | r/Machinists (shelvock86) |
| R-11 | 08-09 | 001 | Add "(PARALLEL TO DATUM A)" to 4 +0.3/0 CTQ | a directed wall thickness needs a measurement direction | APPLIED | r/Machinists (shelvock86, Saerylol) |
| R-10 | 08-09 | 001 | Reduce front-view hole dims; drop 7.5/13.1; relocate finish symbols | readability | APPLIED | r/Machinists (shelvock86, archerdynamics) |
| R-9 | 08-09 | 001 | Ra restacked max-over-min; general-finish note; g6 to 3 decimals | B46.1 / Y14.36M self-check | APPLIED | self-check |
| R-8 | 08-07 | 001 | Remove spurious Ø91.76 (was measuring the outer wall) | Phase-8 audit finding 6 | APPLIED | self-check |
| R-7 | 08-06 | 000 | BOM to solution-annealed; fastener to ISO 4014; gasket = reinforced flexible graphite | Phase-8 self-check | APPLIED | self-check |
| R-6 | 08-04 | 002 | Recess depth 4.0 to 4.5 (Fix A) | Stack 3: prevent spigot-tip bottoming on the recess floor (worst-case gap -0.05 to +0.45) | APPLIED | phase5/stackup §3 |
| R-5 | 08-04 | 001, 002 | Bolt position ⌀1.0 to ⌀0.9 Ⓜ | Stack 2b: assembly guaranteed independent of MMC bonus | APPLIED | phase5/stackup |
| R-4 | 08-04 | 001 | Throat-wall band reconciled to 4 +0.3/0 | Stack 1; the drawing already carried +0.3, so the **docs** were updated, no sheet change | APPLIED (doc-side) | phase5/stackup §1 |
| R-3 | 08-01 | 001 | Inner contour = profile ⌓0.2 A\|B + total runout ⌰0.05 A\|B | runout holds coaxiality to 0.025; profile-only and composite fail the concentricity stack | APPLIED | self-check |
| R-2 | 07-31 | 001 | Spigot 4.00 to 4.75; R1.5 fillet | assembly finding: register engagement was 0 mm (4.00 - 1.5 gasket - 0.75 chamfer) | APPLIED | self-check |
| R-1 | 07-30 | 001, 002 | Datum scheme committed: A\|B (A = seal face, B = pilot Ø92.80), no C; floating-fastener position; joint = 8 x M8 | Phase-3 gate cross-check | APPLIED | self-check |

---

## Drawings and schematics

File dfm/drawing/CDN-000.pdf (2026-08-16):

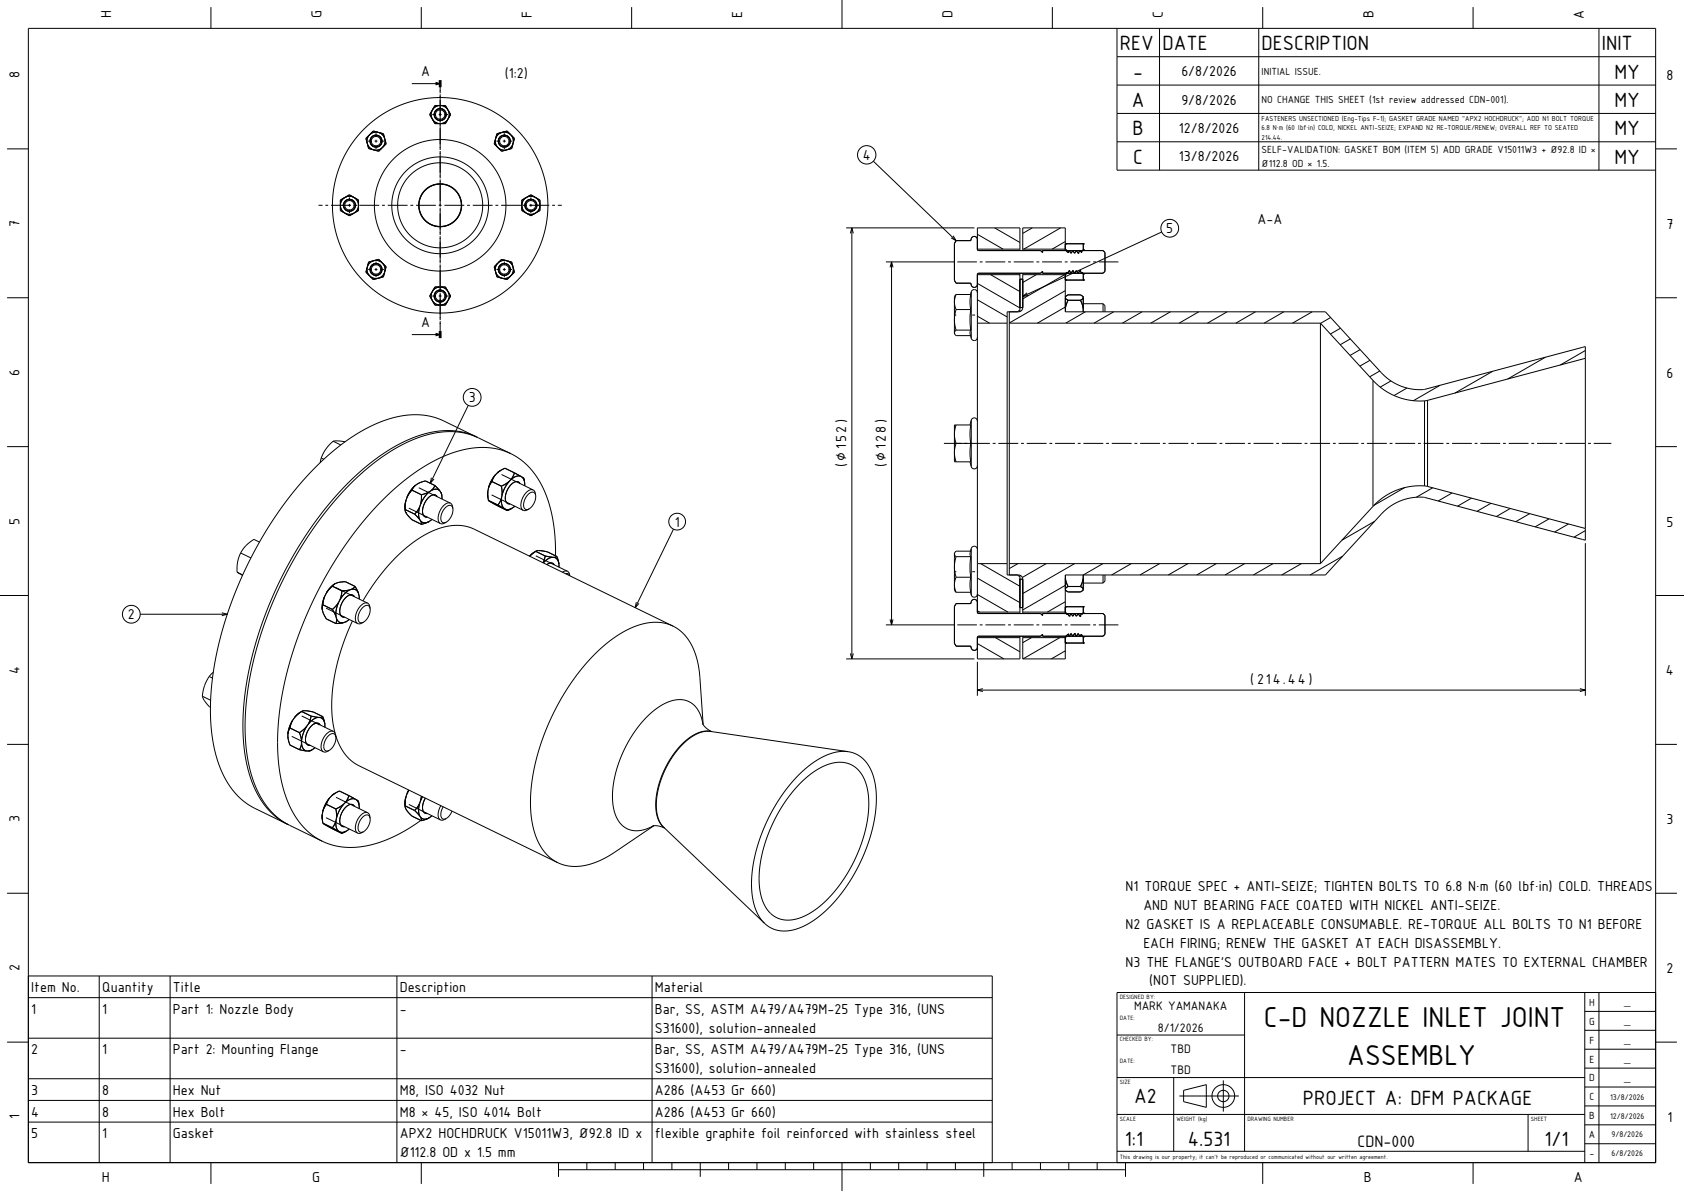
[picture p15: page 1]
Hex Nut; M8, ISO 4032 Nut; Gasket; APX2 HOCHDRUCK V15011W3, Ø92.8 ID x; WEIGHT (kg); DRAWING NUMBER; PROJECT A: DFM PACKAGE; CHECKED BY:

REV | DATE | DESCRIPTION | INIT

- | 6/8/2026 | INITIAL ISSUE. | MY

A | 9/8/2026 | NO CHANGE THIS SHEET (1st review addressed CDN-001). | MY
B | 12/8/2026 | FASTENERS UNSECTIONED (Eng-Tips F-1); GASKET GRADE NAMED "APX2 HOCHDRUCK"; ADD N1 BOLT TORQUE 214.44. MY 6.8 N·m (60 lbf·in) COLD, NICKEL ANTI-SEIZE; EXPAND N2 RE-TORQUE/RENEW; OVERALL REF TO SEATED
C | 13/8/2026 | SELF-VALIDATION: GASKET BOM (ITEM 5) ADD GRADE V15011W3 + Ø92.8 ID × Ø112.8 OD × 1.5. | MY

N1 TORQUE SPEC + ANTI-SEIZE; TIGHTEN BOLTS TO 6.8 N·m (60 lbf·in) COLD. THREADS
AND NUT BEARING FACE COATED WITH NICKEL ANTI-SEIZE.
N2 GASKET IS A REPLACEABLE CONSUMABLE. RE-TORQUE ALL BOLTS TO N1 BEFORE
EACH FIRING; RENEW THE GASKET AT EACH DISASSEMBLY.
N3 THE FLANGE'S OUTBOARD FACE + BOLT PATTERN MATES TO EXTERNAL CHAMBER
(NOT SUPPLIED).

Item No. | Quantity | Title | Description | Material
1 | 1 | Part 1: Nozzle Body | - | Bar, SS, ASTM A479/A479M-25 Type 316, (UNS S31600), solution-annealed

DESIGNED BY: MARK YAMANAKA 8/1/2026 DATE: | C-D NOZZLE INLET JOINT ASSEMBLY | H | _

C | 13/8/2026
B | 12/8/2026

2 | 1 | Part 2: Mounting Flange | - | Bar, SS, ASTM A479/A479M-25 Type 316, (UNS S31600), solution-annealed

4 | 8 | Hex Bolt | M8 × 45, ISO 4014 Bolt | A286 (A453 Gr 660)

flexible graphite foil reinforced with stainless steel

This drawing is our property; it can't be reproduced or communicated without our written agreement.

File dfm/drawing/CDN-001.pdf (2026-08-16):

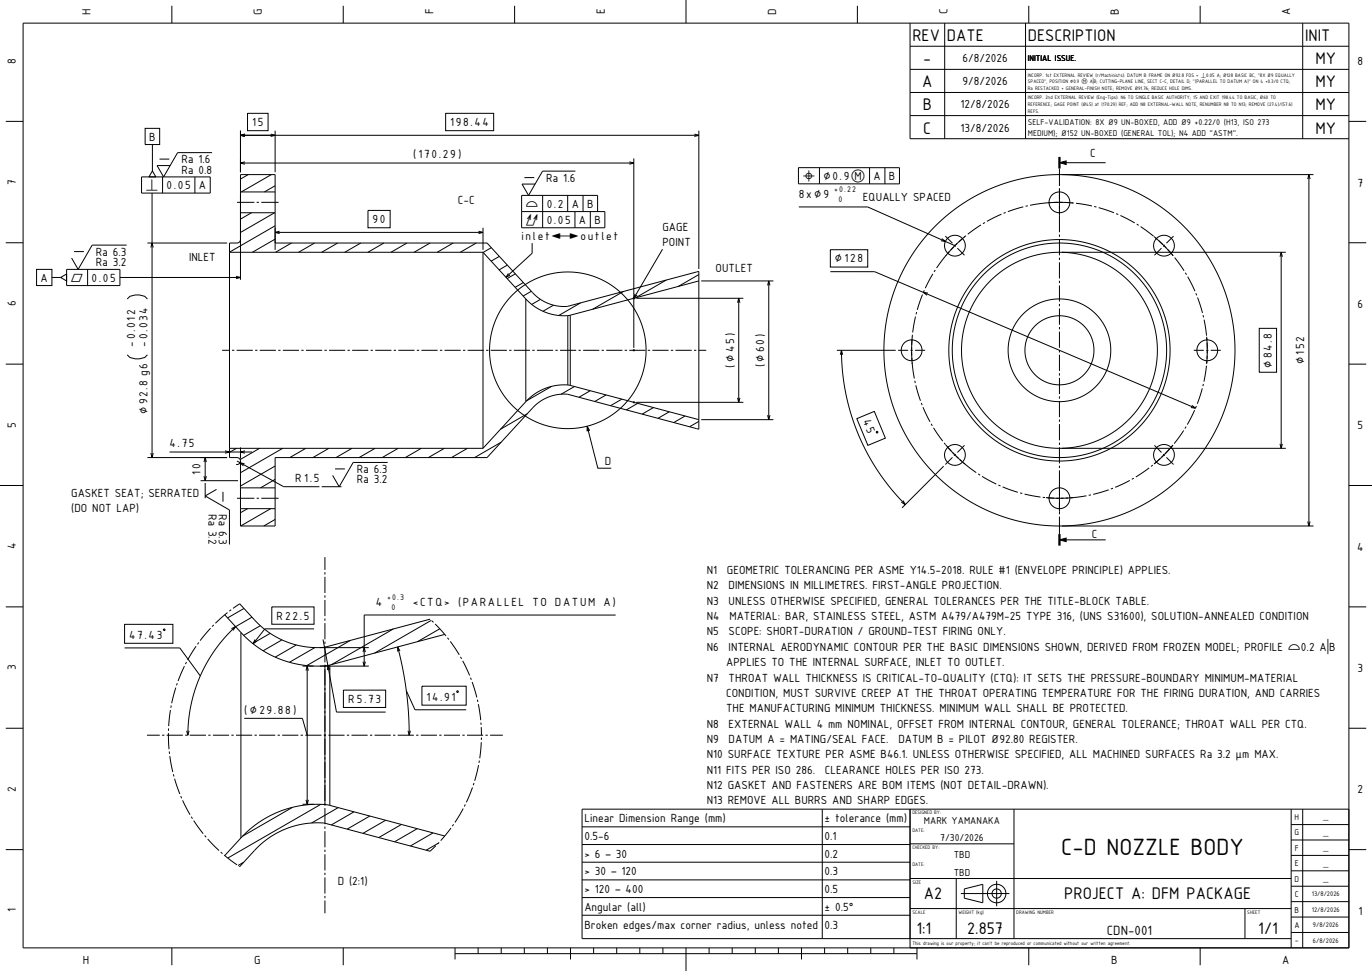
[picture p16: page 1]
WEIGHT (kg); DRAWING NUMBER; EQUALLY SPACED; <CTQ> (PARALLEL TO DATUM A)

REV | DATE | DESCRIPTION | INIT

- | 6/8/2026 | INITIAL ISSUE. | MY
A | 9/8/2026 | INCORP. 1st EXTERNAL REVIEW (r/Machinists): DATUM B FRAME ON Ø92.8 FOS + ⊥0.05 A; Ø128 BASIC BC, "8X Ø9 EQUALLY SPACED", POSITION ⌀0.9 Ⓜ A|B; CUTTING-PLANE LINE, SECT C-C, DETAIL D; "(PARALLEL TO DATUM A)" ON 4 +0.3/0 CTQ; Ra RESTACKED + GENERAL-FINISH NOTE; REMOVE Ø91.76; REDUCE HOLE DIMS. | MY
B | 12/8/2026 | INCORP. 2nd EXTERNAL REVIEW (Eng-Tips): N6 TO SINGLE BASIC AUTHORITY; 15 AND EXIT 198.44 TO BASIC, Ø60 TO REFS. REFERENCE; GAGE POINT (Ø45) at (170.29) REF; ADD N8 EXTERNAL-WALL NOTE, RENUMBER N8 TO N13; REMOVE (27.4)/(57.6) | MY
C | 13/8/2026 | SELF-VALIDATION: 8X Ø9 UN-BOXED, ADD Ø9 +0.22/0 (H13, ISO 273 MEDIUM); Ø152 UN-BOXED (GENERAL TOL); N4 ADD "ASTM". | MY

GASKET SEAT; SERRATED
(DO NOT LAP)

N1 GEOMETRIC TOLERANCING PER ASME Y14.5-2018. RULE #1 (ENVELOPE PRINCIPLE) APPLIES.
N2 DIMENSIONS IN MILLIMETRES. FIRST-ANGLE PROJECTION.
N3 UNLESS OTHERWISE SPECIFIED, GENERAL TOLERANCES PER THE TITLE-BLOCK TABLE.
N4 MATERIAL: BAR, STAINLESS STEEL, ASTM A479/A479M-25 TYPE 316, (UNS S31600), SOLUTION-ANNEALED CONDITION
N5 SCOPE: SHORT-DURATION / GROUND-TEST FIRING ONLY.
N6 INTERNAL AERODYNAMIC CONTOUR PER THE BASIC DIMENSIONS SHOWN, DERIVED FROM FROZEN MODEL; PROFILE ⌓0.2 A|B
APPLIES TO THE INTERNAL SURFACE, INLET TO OUTLET.
N7 THROAT WALL THICKNESS IS CRITICAL-TO-QUALITY (CTQ): IT SETS THE PRESSURE-BOUNDARY MINIMUM-MATERIAL
CONDITION, MUST SURVIVE CREEP AT THE THROAT OPERATING TEMPERATURE FOR THE FIRING DURATION, AND CARRIES
THE MANUFACTURING MINIMUM THICKNESS. MINIMUM WALL SHALL BE PROTECTED.
N8 EXTERNAL WALL 4 mm NOMINAL, OFFSET FROM INTERNAL CONTOUR, GENERAL TOLERANCE; THROAT WALL PER CTQ.
N9 DATUM A = MATING/SEAL FACE. DATUM B = PILOT Ø92.80 REGISTER.
N10 SURFACE TEXTURE PER ASME B46.1. UNLESS OTHERWISE SPECIFIED, ALL MACHINED SURFACES Ra 3.2 µm MAX.
N11 FITS PER ISO 286. CLEARANCE HOLES PER ISO 273.
N12 GASKET AND FASTENERS ARE BOM ITEMS (NOT DETAIL-DRAWN).
N13 REMOVE ALL BURRS AND SHARP EDGES.

Linear Dimension Range (mm) | ± tolerance (mm) | DESIGNED BY: MARK YAMANAKA DATE: 7/30/2026 | C-D NOZZLE BODY | H | _
0.5-6 | 0.1
> 6 – 30 | 0.2 | CHECKED BY: TBD DATE: TBD
> 30 – 120 | 0.3
> 120 – 400 | 0.5 | SIZE A2 | | | | | PROJECT A: DFM PACKAGE
Angular (all) | ± 0.5°
Broken edges/max corner radius, unless noted | 0.3 | | | | | A | 9/8/2026

C | 13/8/2026
B | 12/8/2026

This drawing is our property; it can't be reproduced or communicated without our written agreement.

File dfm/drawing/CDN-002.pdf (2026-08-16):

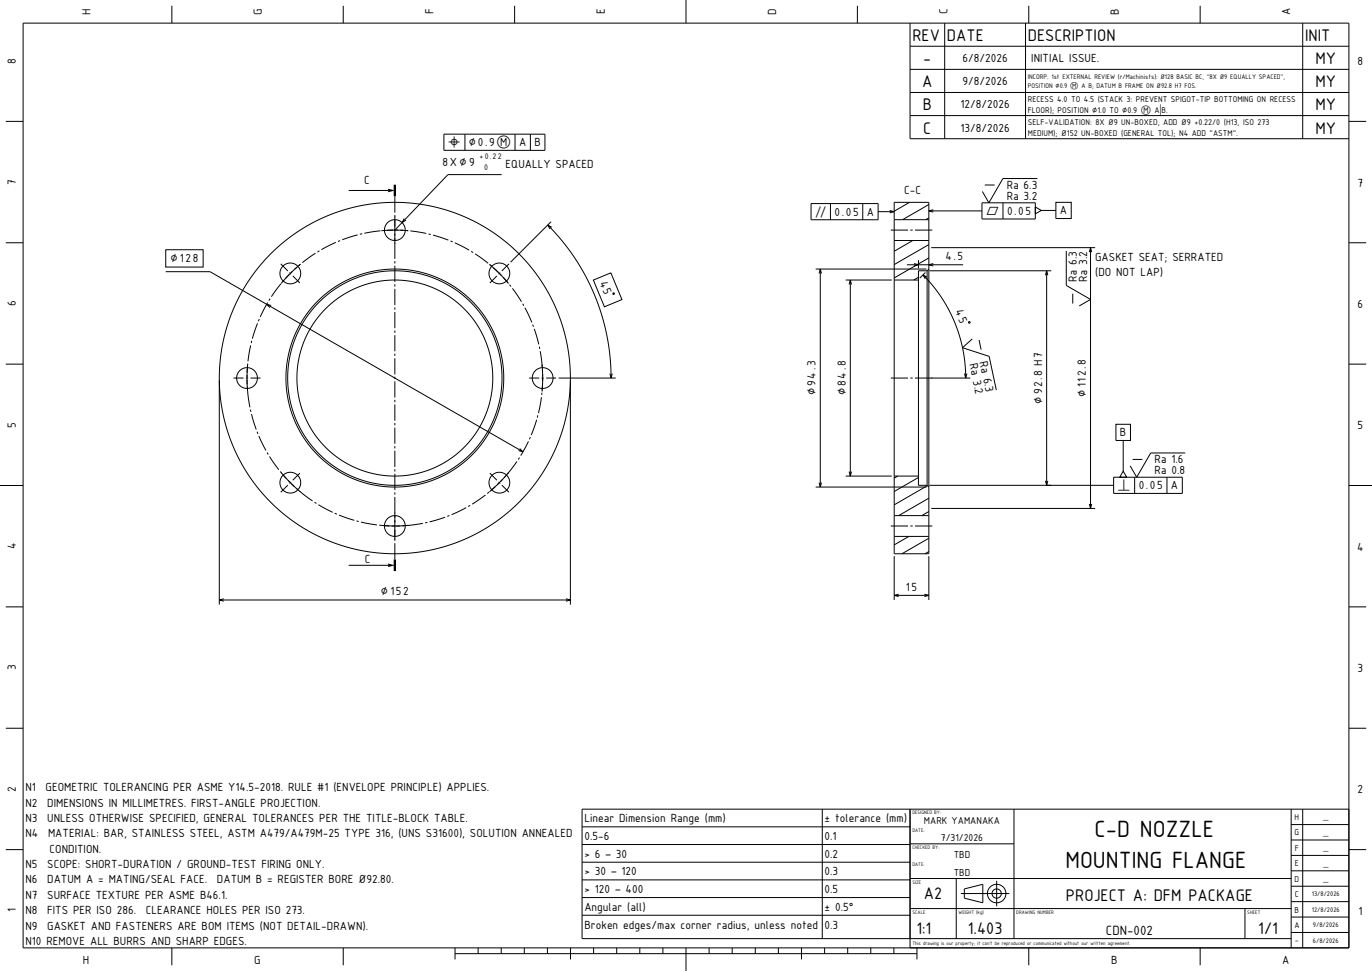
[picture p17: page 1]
WEIGHT (kg); DRAWING NUMBER; EQUALLY SPACED

REV | DATE | DESCRIPTION | INIT
- | 6/8/2026 | INITIAL ISSUE. | MY
A | 9/8/2026 | INCORP. 1st EXTERNAL REVIEW (r/Machinists): Ø128 BASIC BC, "8X Ø9 EQUALLY SPACED", POSITION ⌀0.9 Ⓜ A B; DATUM B FRAME ON Ø92.8 H7 FOS. | MY
B | 12/8/2026 | RECESS 4.0 TO 4.5 (STACK 3: PREVENT SPIGOT-TIP BOTTOMING ON RECESS FLOOR); POSITION ⌀1.0 TO ⌀0.9 Ⓜ A|B. | MY
C | 13/8/2026 | SELF-VALIDATION: 8X Ø9 UN-BOXED, ADD Ø9 +0.22/0 (H13, ISO 273 MEDIUM); Ø152 UN-BOXED (GENERAL TOL); N4 ADD "ASTM". | MY

GASKET SEAT; SERRATED
(DO NOT LAP)

N1 GEOMETRIC TOLERANCING PER ASME Y14.5-2018. RULE #1 (ENVELOPE PRINCIPLE) APPLIES.
N2 DIMENSIONS IN MILLIMETRES. FIRST-ANGLE PROJECTION.
N3 UNLESS OTHERWISE SPECIFIED, GENERAL TOLERANCES PER THE TITLE-BLOCK TABLE.
N4 MATERIAL: BAR, STAINLESS STEEL, ASTM A479/A479M-25 TYPE 316, (UNS S31600), SOLUTION ANNEALED
CONDITION.
N5 SCOPE: SHORT-DURATION / GROUND-TEST FIRING ONLY.
N6 DATUM A = MATING/SEAL FACE. DATUM B = REGISTER BORE Ø92.80.
N7 SURFACE TEXTURE PER ASME B46.1.
N8 FITS PER ISO 286. CLEARANCE HOLES PER ISO 273.
N9 GASKET AND FASTENERS ARE BOM ITEMS (NOT DETAIL-DRAWN).
N10 REMOVE ALL BURRS AND SHARP EDGES.

Linear Dimension Range (mm) | ± tolerance (mm) | DESIGNED BY: MARK YAMANAKA 7/31/2026 DATE: | C-D NOZZLE MOUNTING FLANGE | H | _
0.5-6 | 0.1
> 6 – 30 | 0.2 | CHECKED BY: TBD DATE: TBD
> 30 – 120 | 0.3
> 120 – 400 | 0.5 | SIZE A2 | | | | | PROJECT A: DFM PACKAGE
Angular (all) | ± 0.5°
Broken edges/max corner radius, unless noted | 0.3 | | | | | A | 9/8/2026

C | 13/8/2026
B | 12/8/2026

This drawing is our property; it can't be reproduced or communicated without our written agreement.

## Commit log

2026-05-25 Initial commit: C-D nozzle multiphysics feasibility study
    [conical_v1_sketch.SLDPRT, conical_v1_sketch.STEP, mesh2_mesh_data.stl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]
2026-07-21 Freeze nozzle geometry on as-built contour; correct half-angle docs
    [conical_v1_sketch.SLDPRT, conical_v1_sketch.STEP]
2026-09-03 Implemented v2.0
    [mesh2_mesh_data.stl, mesh3_mesh_data.stl]
